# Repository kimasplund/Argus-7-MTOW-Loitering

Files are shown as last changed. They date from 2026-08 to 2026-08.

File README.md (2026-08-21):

Clude and Kimi decided to have a drone baby over night from som questions i asked in group chat about a project kimi swarm chewed over. Seems to be fairly well optimized airframe. Maybe usefull for someone, or maybe its just garbage.

# ARGUS-7 — Persistent Disaster-Zone Communications & Survey UAV

Long-endurance fixed-wing UAV carrying a 50 kg multi-role bay (LTE/5G relay +
EO/IR gimbal + mesh/satcom backhaul) over a disaster zone, recovered by parachute
and airbag for reuse.

**Status:** paper design with a reproducible model behind it. Nothing flight-tested,
no CFD, no structural test. 459 tests pass; 12 xfails document real defects in the
published design rather than broken tests.

## The aircraft

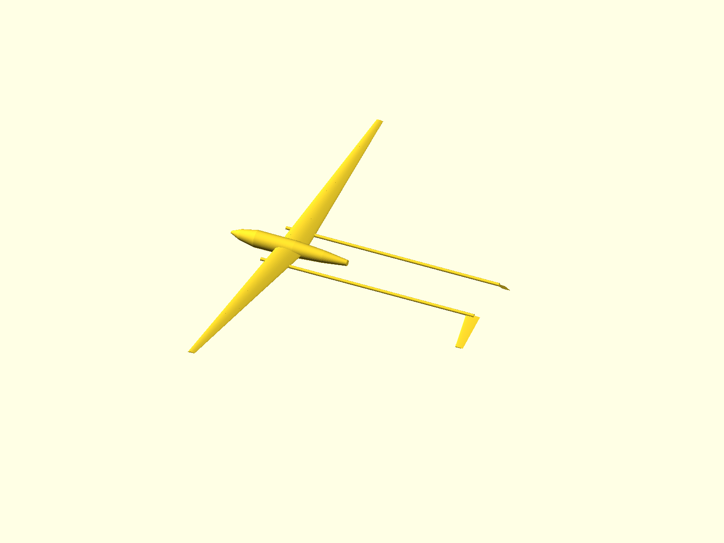
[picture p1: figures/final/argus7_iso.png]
ARGUS-7 v5.0 isometric


| | |
|---|---|
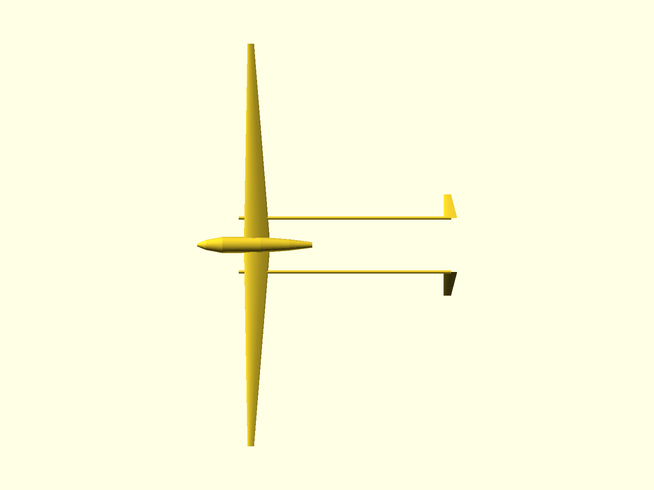
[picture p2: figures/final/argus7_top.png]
top
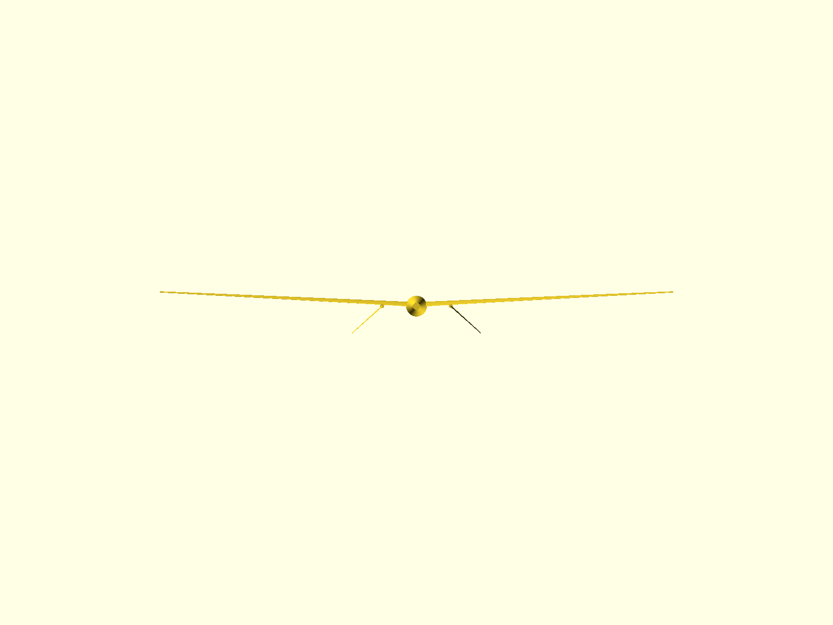
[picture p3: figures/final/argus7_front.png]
front
|  |  |

**v5.0** — 6.97 d loiter, 320 kg MTOW, 11.86 m span, 5.72 m² wing at AR 24.6,
10.85 kW engine driving a 1.04 m two-blade propeller at 2050 rpm through 3.66:1.
Static margin +12.72% full / +13.68% dry. **Passes 8 of 9 adoption gates** — G7
(buildability) fails because its 251 g/kWh full-load BSFC is a design *target*,
not a verified figure for any engine on the report's shortlist; the nearest
verified units are 330 g/kWh.

The wing sits at 41% of fuselage length, not the 22% the published design used.
That single change is what makes it balance, and it also puts the tanks at the CG,
so CG travel across the whole fuel burn is +0.94% MAC.

Renders regenerate from `design/argus7_v5.yaml` via `scripts/build_model.py`.
**These depict a paper design that has never been built or flown**, and
`docs/argus7_v3_premortem.md` lists what would have to be true for it to fly.

## Performance

Two different missions, two different speeds. Endurance flies at minimum *power*;
range flies at minimum *drag*. You do not get both from one flight.

| | Loiter mission | Ferry mission |
|---|---|---|
| **Endurance** | **166.6 h (6.94 d)** | 131.8 h |
| **Range** | — | 17,659 km **(not currently flyable — see below)** |
| Speed | ~102 km/h TAS | 134 km/h TAS |
| Best-range band | — | 124–146 km/h (within 1%) |
| L/D max | 30.4 at C_L 1.028 | |

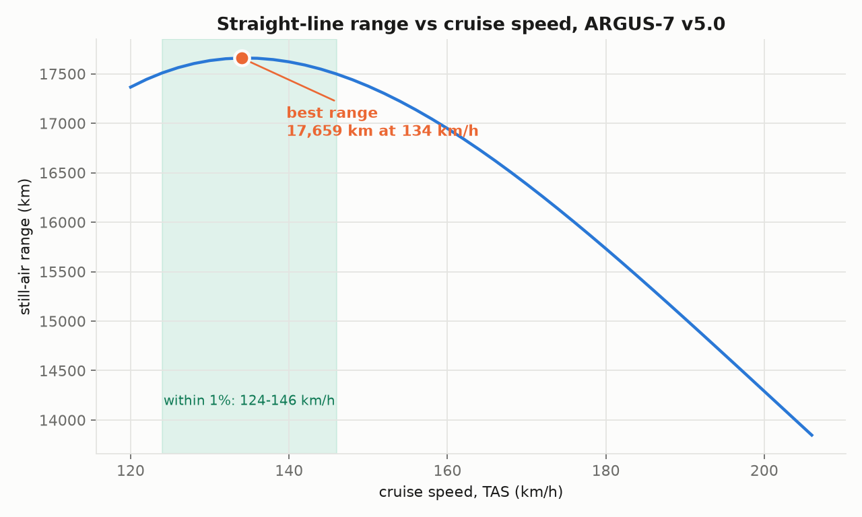
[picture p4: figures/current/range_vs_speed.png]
range vs speed


The range optimum sits *faster* than textbook L/D would put it, because BSFC
depends on engine load fraction — cruising harder works the engine into a better
part of its curve.

**What 17,659 km reaches**, from a mid-Europe base: Lisbon 19%, New York 37%,
Tokyo 44%, Cape Town 56%, Sydney 86%. Earth's circumference is 227% — no.

**Sanity check:** Vanilla VA001's 8-day world record at 191 kg is roughly
19,300 km of air distance if flown straight, so this is the same order as a real
aircraft of the class. It is *not* the discredited 16,000 km claim from the
originating session revived — that was 200 kg on BSFC 230 g/kWh with no stall
margin; this is 320 kg on ~310 g/kWh part-load with the stall margin active.

**The range figure is not flyable with the propeller as specified.** Reaching
134 km/h at MTOW needs 2,500 prop rpm, i.e. 9,148 crank rpm through the 3.66:1
reduction — **122% of the assumed 7,500 rpm rating**. The fixed-pitch disc was
selected for the loiter point and tops out near 122 km/h at MTOW, leaving much of
the installed power unusable in cruise. The loiter mission is unaffected. This is
the case where the earlier "variable pitch buys nothing" conclusion stops holding:
it was true for loiter, and is false for the ferry mission.

**Other caveats:** still air (a 30 km/h headwind costs 22% of range); no reserve,
climb, descent or diversion, fuel burned to dry tanks; and 102 km/h does not close
at MTOW — the loiter speed only becomes available once fuel has burned off.
Regenerate with `scripts/range_analysis.py`.

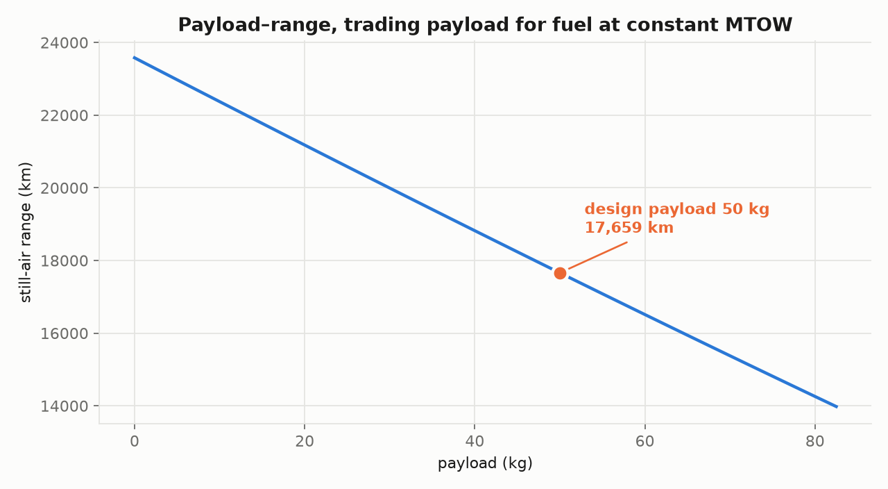
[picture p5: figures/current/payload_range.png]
payload-range


## Start here

- **[docs/decisions/](docs/decisions/)** — what was found, decided and corrected,
  with the reasoning and the cost of being wrong for each.
- **[docs/argus7_design_report.md](docs/argus7_design_report.md)** — the original
  v1.0 report. **Superseded**: it publishes a statically unstable aircraft. Kept as
  the historical record.
- **[design/](design/)** — the design points. See the lineage below.

## Design lineage

These are not variants of one aircraft; they are successive corrections.

| File | Endurance | Status |
|---|---|---|
| `argus7_v1.yaml` | 4.70 d published, **3.16 d** measured | **Published, defective.** Statically unstable (−44% → −82% MAC), wing cannot hold its fuel, propeller cannot absorb its engine |
| `argus7_v2.yaml` | 4.88 d | **RETIRED.** Unstable (−8.7% → −23.5%), mass budget 13 kg short |
| `argus7_v3.yaml` | 6.33 d | **Superseded.** Balances, but at +5.79% MAC — below the spec's own 8% floor |
| `argus7_v4.yaml` | 6.99 d | **Superseded.** Balances, but span 12.001 m against a 12.0 m limit — zero buildable margin, fails gate G3 |
| `argus7_v5.yaml` | **6.94 d** | **Current. 8/9 gates** — G7 fails on an unverified engine BSFC. Span 11.856 m (144 mm margin), SM +12.72% / +13.68%, mass closes exactly |

Every design point is machine-checked: geometry closure, provenance tags on every
parameter, and a static-margin verification against `argus7/analysis/balance.py`.

## The five findings that moved the numbers

1. **The engine is the biggest lever, not the airframe.** v1.0 installs 17 kW for
   climb, then loiters at 3.4 kW — **19% load, where BSFC is 425 g/kWh, not the
   assumed 270**. Right-sizing to ~11 kW is worth more than every aerodynamic
   refinement combined.
2. **The aircraft did not balance, and nobody had checked.** Static margin
   −44% MAC at full fuel. The report's published "+14.7% at CG 42%" does not
   reproduce; the *neutral point* half of that same line does, so the 42% CG was an
   assumed target no mass build-up supports. Fixed by moving the wing station from
   `x_le_frac` 0.22 to ~0.42.
3. **The wing could not hold its own fuel.** 101.5 kg required against 66 kg of
   capacity. Fixed by a larger, thicker wing — which also buys spar depth, so empty
   mass barely moves.
4. **The propulsion set did not close.** A 0.813 m prop at 2100 rpm needs
   C_P = 0.911 against a ~0.25 ceiling. It was a symptom of the oversized engine:
   at 11 kW an ordinary 1.04 m two-blade prop absorbs it comfortably.
5. **Aspect ratio is not the lever the design was built around.** Span efficiency
   is nearly flat in AR (0.989 at AR 14 to 0.969 at AR 30, measured across 45 AVL
   runs), so the only real cost of aspect ratio is structural mass.

## Layout

```
argus7/
  design/    parameter schema, geometry derivation, closure guards
  cad/       aerofoil coordinates, build123d model, STEP/STL/OpenSCAD export
  aero/      XFOIL driver, NeuralFoil surrogate, component drag build-up
  prop/      engine power and part-load BSFC, BEMT propeller
  mission/   ISA atmosphere and the batched differentiable mission simulator
  opt/       design space, mass model, geometry coupling, layout, optimiser
  analysis/  CG, neutral point, static margin (AVL-cross-checked)
research/    materials, riblets, boom construction, empennage trade, hypotheses
docs/decisions/   rulings, findings, gauntlet pre-registration and audit
scripts/     setup_env.sh, build_model.py, optimiser runs, mutation_test.py
opt_runs/    raw output of every optimisation run
```

## Reproducing

```bash
./scripts/setup_env.sh                      # xfoil, avl, gmsh, calculix, SU2, openscad, venv
PYTHONPATH=. .venv/bin/pytest tests/ -q     # 459 pass, 12 xfail
PYTHONPATH=. .venv/bin/python scripts/build_model.py    # regenerate CAD from design/argus7_v1.yaml
PYTHONPATH=. .venv/bin/python scripts/mutation_test.py  # test the tests
```

The mission simulator reproduces the closed-form Breguet solution to **0.0000%**
and the published v1.0 endurance to **+0.2%**. It runs 40 M designs in 4.6 s on a
12 GB GPU with exact gradients through the fuel-burn integration.

## Figures

| Path | Status |
|---|---|
| `figures/cad/` | v1.0 renders, regenerated by `scripts/build_model.py` |
| `figures/cad_v2/` | v2.0 renders — **v2.0 is retired**, kept only for comparison |
| `figures/argus7_3view.png`, `argus7_performance.png` | v1.0 era, from the originating session. **Not regenerable** — the code did not survive |
| `figures/design-pack/fig1`–`fig9` | The 200 kg AR-20 predecessor, a different aircraft. **Not regenerable** |
| `figures/final/` | v5.0 renders, regenerated by `scripts/build_model.py` |
| `figures/current/` | Static margin, part-load BSFC, endurance, drag split, range, payload–range — all regenerated by `scripts/make_figures.py` and `scripts/range_analysis.py` |

## Known gaps

- **The MTOW scaling law is not determined.** Three fits of the same quantity give
  exponents 0.869, 0.998 and 1.452 depending on the subset. Only engine power scales
  cleanly (MTOW^0.82, 6.1% scatter) because climb pins it; span, area and aspect
  ratio scatter 20–31% because the objective is genuinely flat in those directions.
  See [docs/decisions/2026-08-21-scaling-not-determined.md](docs/decisions/2026-08-21-scaling-not-determined.md).
- **Report §2's tail row does not close:** V_h is 0.5765, not the stated 0.68.
  Tracked as an xfail.
- **Two of the report's three sensitivity anchors are wrong:** BSFC 250 gives
  +0.377 d, not +0.5 d; 3,000 m gives +0.198 d, not +0.23 d. Only the C_D0 anchor
  reproduces.
- **The performance analysis behind the v1.0 report is not reproducible** — the code
  did not survive the originating session. The CAD and the current mission model are.
- **The endurance case rests on a BSFC measurement nobody has made.** 335 g/kWh at
  ~31% load is modelled, not dyno-mapped.
- Model limits on every endurance number: pure loiter only (no transit, climb or
  reserve), fuselage fixed at 3.4 m, non-wing airframe mass fixed at 28 kg
  regardless of wing size, mass model calibrated on a single point.
- Regulatory treatment is EU headline level only, and the current design point sits
  **above** the 250 kg band the original occupied.

## Verified non-issues

- **Propeller/boom clearance.** The booms sit outboard of the prop disc and move
  outboard automatically with wing span, because `booms.y_station_frac` is a
  fraction of semi-span. Clearance is 169 mm on v1.0 and improves on later points.
- **The booms are not in the propwash.** An earlier revision of this file claimed
  they were. They clear the contracted slipstream by 183–209 mm, giving a vibratory
  strain of 0.011% against a 0.6% matrix fatigue limit — a 55× margin. The design
  action is a prohibition (no structure inside r = 0.45 m aft of the disc), not a
  layup constraint.
- **Wing thickness at 20%** costs +15.8% on wing profile drag and *raises* C_Lmax
  from 1.868 to 1.973. Measured on the real coordinates, not assumed.

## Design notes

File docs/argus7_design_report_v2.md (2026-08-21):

# ARGUS-7 — Persistent Disaster-Zone Communications & Survey UAV
## Engineering Design Report (v2.0 of the report; design point v5.0)

**Date:** 2026-08-21 · **Design point:** `design/argus7_v5.yaml` (variant tag `v5.0`)
**Status:** Paper design. Nothing here has been built, flown, wind-tunnel tested, or meshed for CFD.
There is now a first pass of structural analysis (§6) — analytic, cross-validated, and
carrying one finding that makes the mass model optimistic. The finite-element model
built alongside it **does not reproduce the cross-validated answer and its numbers are
not used anywhere in this report.**

---

> ### This report supersedes `docs/argus7_design_report.md` (v1.0).
>
> That document remains in the repository as the historical record and must not be
> edited. It should not be used as a design reference. It publishes an aircraft that
> is **statically unstable at every fuel state** (−44.0% MAC full, −82.2% MAC dry),
> whose **wing cannot hold its own fuel** (101.5 kg required into 66.1 kg of tank),
> whose **propeller cannot absorb its engine** (C_P 0.911 demanded against a ~0.25
> practical ceiling), whose **§2 tail row does not close** (V_h 0.5765, not the stated
> 0.68), and **two of whose three published sensitivity anchors are wrong**. Its
> headline 4.70-day endurance is 3.16 days once the engine is modelled at the load it
> actually runs at instead of assumed. Every one of those statements is measured, and
> §10 gives the arithmetic and the file for each.

> ### An earlier revision of *this* report published v3.0. That design point is superseded twice over.
>
> v3.0 balanced, but at **+5.79% MAC** — below the programme's own pre-registered 8%
> static-margin floor, because the optimiser had been run with a 5–15% window instead
> of the spec's 8–20%. v4.0 fixed the stability gate and then landed at **12.0015 m of
> span against a 12.0 m limit** — 1.5 mm over, which is zero buildable margin and a
> failed gate G3. **v5.0 is the current design point.** Every number in this report is
> v5.0's unless it is explicitly labelled otherwise. §9 gives the lineage.

---

## 0. Executive summary

ARGUS-7 v5.0 is a 320 kg MTOW, single-engine, high-aspect-ratio, twin-boom pusher UAV
sized to loiter over a disaster zone carrying a 50 kg / 500 W multi-role
communications and survey bay, recovered by parachute. It is the output of an
11-variable optimiser that owns the **layout** as well as the wing, and that treats
longitudinal static margin, wing fuel volume, climb power and span as hard
constraints rather than as things checked afterwards.

| Headline | Value | Where it comes from | The caveat, stated next to it |
|---|---|---|---|
| **Loiter endurance** | **6.97 d (167.3 h)** | `opt_runs/layout_final.json` (`refined`), reproduced here to 167.325 h from the recorded design variables | **Pure loiter only** — no transit, climb, reserve or wind. The recorded figure is computed at **η_prop 0.858**, hardcoded in the run script; at the propeller efficiency **the design file itself records (0.8529)** it is **166.56 h (6.94 d)**, and with BSFC evaluated pointwise across the burn rather than frozen, **159.98 h (6.67 d)**. See §7.3 |
| Loiter altitude | 4,000 m | optimiser variable, at the lower bound of the run that produced this point | Inside the sponsor-locked 3,000–4,500 m band. Coverage 10.81 km radius / 367 km², on v1.0 §8's own unvalidated elevation model — the same as v1.0's design point, and 16% less area than v3.0's 4,359 m |
| MTOW | 320.00 kg | `design/argus7_v5.yaml`, and it is **at the optimiser's upper bound** | **+28% on v1.0's 250 kg.** This crosses the mass band v1.0 §9's entire regulatory case was built at. Declared here, see §12.4 |
| Wing | 5.7201 m², AR 24.573, span 11.8558 m, taper 0.25, t/c 0.220 | design file; closure verified by `argus7.design.geometry` to 1e−9 | Span is inside the 12 m transport gate with **144 mm** of margin. **Taper 0.25 and t/c 0.22 are both outside the ranges the aero surrogates were fitted over** — §3.4, §3.5 |
| Static margin | **+12.72% MAC full, +13.68% dry**, travel **+0.95% MAC** | `argus7.analysis.balance` on the design file | **Inside the spec's 8–20% MAC window on all four readings available** (+8.23% to +17.96%, §5.4) at both fuel states. This is the first design point in the programme of which that is true |
| Fuel | 172.42 kg into a 190.44 kg wing tank | `argus7.opt.design_space.wing_fuel_capacity_kg` | **+18.02 kg (10.4%) margin**, against v3.0's 4.4%. Survives mogas density (+5.5%) where v3.0 did not — §12.2. The capacity model is three fractions, two of them measured, not a lofted cavity |
| Mass closure | **0.00 kg** residual on 320.00 kg | `argus7.analysis.balance.mass_budget_residual_kg` | Exact to the design file's own precision |
| Engine | 10.849 kW rated, 30.0% loiter load, **effective BSFC 339.3 g/kWh** | optimiser; cross-checked against `argus7.prop.engine`, which gives 350.1 g/kWh at the same shaft power (3.2% apart) | The 339 rests on a **full-load BSFC of 250 g/kWh, which is the report's aspirational dyno target, not a measured unit.** Both shortlist engines with *verified* BSFC are 330 g/kWh, at which this aircraft flies **5.26 d**, §4.4 |
| Propeller | 1.04 m, 2 blades, 2,050 rpm, p/D 0.95, η 0.8529, 3.659:1 reduction | design file; re-solved at **this** design point, not inherited | **A found-and-fixed defect** — v3.0 carried v2.0's propeller and was 26% short of level-flight thrust (§4.5). v5.0's disc meets loiter thrust and absorbs 101% of the rating at climb. **But it cannot turn fast enough for the ferry mission** — §8.4 |
| C_D0 | 0.01690 | `argus7.opt.coupled.cd0_from_geometry` | Contains **no** payload turret, cooling drag, or base drag. A modest +0.0035 allowance costs **−0.43 d** — §3.2 |
| **Tip deflection at limit** | **855 mm = 14.4% of semi-span** | `scripts/structural_analysis.py`, cross-validated to 0.2 points against `research/materials_pack.md`'s independent estimate | Sailplane territory, not light-aircraft territory. Not disqualifying; it interacts with spanload, control effectiveness and flutter, none of which is modelled coupled — §6.2 |
| **Compression-cap buckling** | **critical at 80 MPa against 600 MPa applied — margin −87%** | `fea_runs/structural.json`, corroborated independently by the cap's width-to-thickness ratio | **The mass model is optimistic.** A buckling-sized cap is heavier than a strength-sized one and wing mass feeds straight into endurance — §6.3 |
| Best range | **17,659 km at 134 km/h TAS**, 131.8 h aloft | `opt_runs/range.json`, `scripts/range_analysis.py` | Still air, no reserve, burned to dry tanks — and **the recorded fixed-pitch propeller and 3.659:1 gearing cannot reach that speed** at the engine's assumed rpm rating, §8.4 |

### The honest bottom line

**v5.0 is the first design point in this programme that passes every closure the
repository can evaluate simultaneously**: it balances, inside the pre-registered
window rather than merely positively; it holds its fuel with real margin; its mass
budget closes exactly; its span is inside the transport gate with buildable margin;
and its propeller was solved at its own operating point instead of inherited from a
retired aircraft. Each of those was false of at least one of v1.0, v2.0, v3.0 and v4.0.

**Two things are still open, and neither is aerodynamic.**

**First, the engine.** 6.97 days is the *optimistic* end of a defensible band, and the
report says so here rather than in a footnote. Stacking the corrections this
repository can already justify:

| Applied cumulatively to the recorded design point | Endurance |
|---|---|
| As recorded (`opt_runs/layout_final.json`, η_prop 0.858) | **167.32 h — 6.97 d** |
| + the propeller efficiency the design file itself records (0.8529) | 166.56 h — 6.94 d |
| + the load fraction recomputed at that efficiency (29.62%, 340.8 g/kWh) | 165.80 h — 6.91 d |
| + BSFC evaluated pointwise along the burn instead of frozen at mid-load | 159.98 h — 6.67 d |
| + a +0.0035 C_D0 allowance for turret, cooling and base drag | 153.69 h — **6.40 d** |
| + a **verified** engine's 330 g/kWh full-load BSFC instead of the 250 target | 116.43 h — **4.85 d** |

**The programme's 5–7 day ambition is met with room to spare on the modelled engine,
and missed — narrowly, at 4.85 days — on the only engines whose fuel consumption
anybody has measured.** That is a materially better position than v3.0, which fell to
4.46 d under the same stack, but it is the same finding: the design lives or dies on a
dyno, not on aerodynamics.

**Second, the structure.** The first structural analysis in the programme's history
(§6) returns a wing that deflects **14.4% of semi-span at limit load** and whose
compression caps buckle at **an eighth of the stress the material allowable assumes**.
The deflection is large but survivable. The buckling is not a caveat, it is a
correction: **the wing mass model is optimistic, and wing mass converts to endurance
at 1.51 h/kg** (§6.5). Nothing in this report has been re-run with a buckling-sized
cap, because sizing one properly is a design task, not an analysis task.

### The pre-registered gates

Unlike every previous revision of this report, this section is short.

Running the eight gauntlet gates (`docs/decisions/2026-08-20-gauntlet-preregistration.md`)
plus the spec's separate stability window against v5.0:

| Gate | v5.0 | Verdict |
|---|---|---|
| G1 endurance ≥ +5% on the champion | 167.3 h vs 75.9 h honest / 112.98 h published | ✅ +48% |
| G2 fuel ≤ wing tank capacity | 172.42 ≤ 190.44 kg (+10.4%) | ✅ |
| G3 span ≤ 12 m | 11.8558 m (144 mm margin) | ✅ |
| G4 mass closure | 0.00 kg residual | ✅ |
| G5 AR^1.5 wing-mass scaling honoured | yes | ✅ |
| G6 regulatory band declared | 320 kg, declared in §12.4 | ✅ |
| G7 buildability: AR ≤ 25, span ≤ 12 m, **engine matched to a real §6 unit** | AR 24.57 ✅, span ✅, **engine is a 250 g/kWh target** | ❌ **FAIL** |
| G8 stall margin | loiter C_L 1.2098 = C_Lmax/1.15² exactly | ✅ (binding) |
| Spec line 109: 8% ≤ SM ≤ 20% MAC | **+12.72% full / +13.68% dry**, and 8.23–17.96% across every reading | ✅ |
| Annex A tripwire #3: loiter BSFC ≤ 300 g/kWh | **339.3 g/kWh modelled** | ❌ **trips** |

**Eight of the nine gates pass. G7 does not, for exactly the reason it did not pass on
v3.0 and on the challenger before it: the design rests on a full-load BSFC of
250 g/kWh that report §6 itself describes as a target, and the gauntlet audit already
ruled that a target is not a unit** (`docs/decisions/2026-08-20-gauntlet-audit.md` §G7).
Nothing about the engine has changed between v3.0 and v5.0; the airframe changed
around it.

**`README.md` currently states that v5.0 passes 9/9. On the repository's own record it
passes 8/9,** and the ninth is the one gate that no amount of optimisation can close.
The honest statement is narrower than "v5.0 is the design": **v5.0 is the best design
point this programme has produced and verified, it clears every airframe gate, and the
one gate it fails is about an engine nobody has put on a dyno.**

---

## 1. Mission and requirements

Unchanged from v1.0 §1. Restated so this document is self-contained.

- **Payload:** 50 kg multi-role bay — LTE/5G relay (eNB plus sector antennas), EO/IR
  gimbal (TrakkaCam TC-300 class), mesh MANET feeder, LEO/Iridium backhaul, mission
  computer and power conditioning. **50 kg / 500 W continuous, ~620 W peak**, all
  COTS-derived. Tagged `report-§1` and `report-§3` in the design file's provenance
  block.
- **Modes:** (A) *Local* — launch near the zone, pure loiter. (B) *Deploy* — transit
  to the zone, loiter, recover locally. **Only mode A is modelled as a mission.**
  Every endurance figure in this report is mode A. §8 adds a straight-line **ferry**
  calculation, which is a third thing and is not mode B either — it has no loiter
  segment at all.
- **Recovery:** parachute plus airbag, reusable airframe, no single-use elements.
- **Environment:** loiter band **3,000–4,500 m AGL**, −5 to −15 °C at altitude.

The loiter band is a locked requirement, and it is treated as one here. The retired
v2.0 optimiser went 500 m *below* the floor to buy 8 hours, giving up 61% of the
coverage area, because nothing in its objective knew coverage existed. The run that
produced v5.0 was bounded at [4,000 m, 4,500 m] and returned **4,000 m** — the floor of
its own search, because at fixed lift coefficient a denser atmosphere means a slower
loiter and less power. **The bound is what stops it going lower, not the physics**, and
that is worth saying plainly: altitude is a coverage requirement fighting an endurance
gradient, and the requirement is winning only because it was written down.

**Coverage at the v5.0 loiter altitude,** on v1.0 §8's own suburban elevation-angle
model (θ* = 20.3°): service radius **10.81 km**, area **367 km²**. That is identical to
v1.0's 4,000 m design point and **16% less area than v3.0's 4,359 m** — a real
regression against the superseded design point, bought for +0.28 d of endurance
(§7.4). The elevation model itself is unchanged and unvalidated; v1.0 §8 already flags
that no published measurement exists in this altitude band.

---

## 2. The v5.0 configuration

### 2.1 Geometry

Every row below is either read directly from `design/argus7_v5.yaml` or derived from
it by `argus7.design.geometry`, which enforces closure to 1e−9. Nothing is typed in.

| Parameter | v3.0 (superseded) | **v5.0** | Provenance |
|---|---|---|---|
| MTOW | 312.93 kg | **320.00 kg** | derived (optimiser); **at its upper bound** |
| Wing area S | 5.9191 m² | **5.7201 m²** | derived |
| Aspect ratio AR | 21.442 | **24.573** | derived |
| Span b | 11.266 m | **11.8558 m** | closure identity √(AR·S) |
| Taper ratio λ | 0.697 | **0.250** | derived — **at the search's lower bound** |
| Root / tip chord | 0.6192 / 0.4316 m | **0.7720 / 0.1930 m** | closure |
| MAC | 0.5310 m | **0.5404 m** | closure |
| MAC leading edge | x = 1.2485 m | **x = 1.4269 m** | derived |
| Wing loading | 52.87 kg/m² | **55.94 kg/m²** | derived |
| Airfoil | FX 63-137 at t/c 0.1909 | **FX 63-137, scaled to t/c 0.2200** | section `report-§2`; thickness derived, **at its upper bound** |
| Twist (tip) / dihedral / LE sweep / incidence | −3° / +3° / 1° / 2° | unchanged | **all four tagged `assumption`** — no source in report or research packs |
| **Wing station `x_le_frac`** | 0.3536 | **0.4075** (root LE at x = 1.3855 m) | **derived — this is the single change that makes the aircraft balance** |
| Wing vertical offset | +8 mm | unchanged | assumption; makes this a mid-wing aircraft |
| Fuselage | 3.4 m × 0.48 m, 6-station loft, 0.4022 m³ | unchanged | **assumption, unchanged from v1.0 and fixed for every design point** |
| Booms | Ø90 mm, y = ±0.7548 m, length 4.064 m | **Ø90 mm, y = ±0.7943 m, length 6.2497 m** | diameter and station `assumption`; length derived |
| Tail | inverted V, −42° dihedral, panel AR 3.0, taper 0.55, NACA 0010 | unchanged | type `report-§2`; angles `assumption` |
| Tail effective horizontal area S_h | 0.3698 m² | **0.3222 m²** | derived |
| Tail arm | 3.5847 m = 1.0543 × L | **5.7732 m = 1.6980 × L** | derived |
| **Tail volume coefficient V_h** | 0.4218 | **0.6018** | derived, and it **closes** — see §10 |
| Engine | 10.845 kW | **10.849 kW**, 250 cc nominal displacement | power derived; displacement inherited `report-§2` |
| Reduction | 3.947 : 1 | **3.659 : 1** | derived |
| Propeller | 1.04 m, 2 blades, 1,900 rpm, p/D 0.95 | **1.04 m, 2 blades, 2,050 rpm, p/D 0.95** | derived (BEMT), **at this design point** |
| Loiter altitude | 4,358.8 m | **4,000.0 m** | derived |

**A note on the tail arm, because it has nearly doubled.** At 1.698 × fuselage length
the tail quarter-chord sits at x = **7.335 m — 3.94 m aft of the 3.4 m fuselage
tailcone**, against v3.0's 1.57 m, carried on booms **6.25 m** long
— 54% longer than v3.0's and 71% longer than the 3.646 m boom on which
`research/boom_construction_pack.md` sized the whole boom structure. That long arm is
what buys V_h 0.6018 and the +29.5% MAC tail contribution the neutral point needs, and
it is what allows a *smaller* tail (0.3222 m² against v3.0's 0.3698) to do more work.
**Every boom number in the research pack is now wrong by more than it was for v3.0.**
The one boom quantity that has been re-derived for v5.0 is torsional frequency, and it
moved: **14.5 Hz against the pack's 22.7 Hz** (§6.6).

**Three of the eleven design variables sit hard against a bound**: MTOW at 320 kg,
t/c at 0.22, taper at 0.25. A fourth, `bsfc_full`, sits at its 0.250 floor. The
premortem's "hidden assumption" finding applies unchanged and with one more variable:
**the answer is partly a description of where the box was drawn.** Taper 0.25 and
t/c 0.22 are additionally *outside the calibration ranges of the aerodynamic
surrogates that price them* (§3.4, §3.5), which is the specific failure class this
report exists to stop repeating.

### 2.2 Mass table

Produced by `argus7.analysis.balance.mass_table` on the design file. The `x` column is
the fuselage station of each group's centre of gravity; `%MAC` is measured from the
MAC leading edge, which is the convention used throughout this report.

| Item | Mass (kg) | x (m) | % MAC | Moment (kg·m) |
|---|---|---|---|---|
| Wing | 40.63 | 1.6430 | 40.0 | 66.75 |
| Fuselage (incl. misc) | 15.06 | 1.6264 | 36.9 | 24.49 |
| Booms | 9.70 | 4.3603 | 542.9 | 42.29 |
| Tail | 3.25 | 7.3833 | 1102.3 | 23.99 |
| Powertrain | 15.95 | 3.0500 | 300.4 | 48.65 |
| Avionics | 6.00 | 1.4500 | 4.3 | 8.70 |
| Recovery | 7.00 | 0.9500 | −88.3 | 6.65 |
| Payload | 50.00 | 0.4320 | −184.1 | 21.60 |
| **Fuel** | **172.42** | **1.6568** | **42.6** | **285.67** |
| **TOTAL** | **320.00** | **1.6524** | **41.7** | **528.78** |

Design-file MTOW 320.00 kg; **unallocated residual 0.00 kg.**

Design-file grouping, for comparison with v1.0 §3:

| Group | v1.0 | v3.0 | **v5.0** |
|---|---|---|---|
| Airframe structure | 60.5 | 73.39 | **68.63** (wing 40.63 + non-wing 28.00) |
| Powertrain | 25.0 | 15.95 | **15.95** (a 10.8 kW engine, not a 17 kW one) |
| Avionics | 6.0 | 6.00 | 6.00 |
| Recovery | 7.0 | 7.00 | 7.00 |
| Payload | 50.0 | 50.00 | 50.00 |
| **Empty (no payload, no fuel)** | **98.5** | 102.34 | **97.58** |
| Fuel | 101.5 (40.6% of MTOW) | 160.60 (51.3%) | **172.42 (53.9% of MTOW)** |
| MTOW | 250.0 | 312.93 | **320.00** |

**v5.0's wing is 4.76 kg lighter than v3.0's on a 3.4% smaller area and a 5.2% larger
span.** That is not an error; it is what a 22% section buys. The spar is 170 mm deep at
the root against v3.0's 118 mm, and depth buys cap area faster than span and weight
consume it (§6.1). It is also, as §6.3 establishes, exactly where the buckling problem
comes from.

**Two assumptions in that table carry the whole thing, and both are declared:**

1. **Non-wing airframe mass is fixed at 28.00 kg** regardless of how large the wing,
   tail or booms become. It was 28 kg on a 3.9 m² wing with a 3.65 m boom and it is
   28 kg on a 5.72 m² wing with a **6.25 m** boom. The mass table above splits that
   28 kg across fuselage/booms/tail for CG purposes only; the total is a constant.
   Charging it honestly — fuselage ∝ MTOW, booms ∝ length, tail ∝ wetted area,
   recovery ∝ MTOW — puts it at roughly **32.9 kg plus an 8.96 kg recovery system**,
   i.e. **about +6.6 kg the model never charges**, and the boom-length term has grown
   since that estimate was made. At the measured exchange rate of **1.51 h/kg** that is
   **−9.8 h, 166.6 → 156.8 h**. This is the same defect the gauntlet audit found on the
   original challenger. It is not fixed here, and v5.0's 6.25 m booms make it worse
   than it was on v3.0.
2. **The wing mass model is calibrated on one point.** `argus7.opt.design_space`
   derives spar-cap mass from root bending moment with a single fitted coefficient
   `k_cal = 4.2257`, set so the model returns v1.0's published 32.5 kg wing. The
   gauntlet audit verified the AR^1.5 exponent analytically and cross-checked the
   *ratio* between two design points against Raymer's independent GA regression to
   1.0% — but it also established that **76% of the spar-cap term at the baseline is
   the fitted constant**. The scaling survives, because `k_cal` is a pure multiplier
   and cancels from every ratio; the absolute level is calibrated, not derived. **And
   §6.3 establishes that the sizing criterion it implements is the wrong one.**

---

## 3. Aerodynamics

### 3.1 The drag polar and the loiter point

The mission model uses the standard lumped polar

    C_D = C_D0 + C_L² / (π · AR · e)

with C_D0 = 0.016904 and e = 0.81012, both **outputs of geometry** in the optimiser's
coupled model rather than free variables. At the loiter point:

| Quantity | v3.0 | **v5.0** |
|---|---|---|
| Loiter C_L | 1.2098 | **1.2098** = C_Lmax / 1.15², stall-constrained |
| C_D | 0.04150 | **0.04030** |
| **L/D at loiter** | 29.15 | **30.02** |
| **L/D max** | — | **30.42 at C_L 1.0281** |
| Induced share of C_D | 61.7% | **58.1%** |
| ρ at loiter altitude | 0.78856 (4,359 m) | **0.81913 (4,000 m)** |
| TAS, MTOW → dry | 118.7 → 82.8 km/h | **119.8 → 81.4 km/h**, mean 101.8 km/h |
| Drag, MTOW → dry | 105.3 → 51.2 N | **104.6 → 48.2 N** |
| Shaft power, MTOW → dry | 4.71 → 2.04 kW | **4.75 → 1.94 kW**, mean 3.26 kW |
| Re at MAC, MTOW → dry | 8.37e5 → 5.84e5 | **8.87e5 → 6.02e5** |
| Re at tip, MTOW → dry | 6.80e5 → 4.75e5 | **3.17e5 → 2.15e5** |

The **stall constraint binds**, as it did on v1.0 and v3.0: unconstrained minimum-power
C_L for this polar is 1.7806, above C_Lmax/1.15², so the aircraft loiters at 1.2098
exactly. This matters, because loiter speed — and therefore power — is set by C_Lmax,
and C_Lmax is held at a flat 1.60 for every design point.

**The tip Reynolds number is the new exposure, and it is a big move.** Taper 0.25 on an
AR 24.57 wing gives a **193 mm tip chord**, and Re at the tip falls to **2.15 × 10⁵ by
the end of the mission** — against v3.0's 4.75 × 10⁵. Low-Reynolds airfoil behaviour
degrades sharply below about 3 × 10⁵, and a flat C_Lmax of 1.60 applied to a wing whose
tip lives there is a stronger assumption than it was.

**Measured, and it survives — in two dimensions.** NeuralFoil (xxlarge) on the pinned
`data/airfoils/fx63137.dat` coordinates scaled to 22% thickness gives 2D C_Lmax:

| Re | 13.7% section | **22% section** |
|---|---|---|
| 2.2 × 10⁵ (tip, dry) | 1.747 | **2.103** ⚠ |
| 3.2 × 10⁵ (tip, MTOW) | 1.770 | **2.118** ⚠ |
| 8.9 × 10⁵ (MAC, MTOW) | 1.871 | **2.154** |
| 1.0 × 10⁶ | 1.869 | **2.163** |

So the flat 1.60 is **conservative by 31% even at the tip's worst Reynolds number** —
thickness buys more C_Lmax than low Reynolds number takes away. ⚠ marks the two rows
where **NeuralFoil flags itself as extrapolating outside its training distribution**
(analysis confidence 0.825 against its own 0.9 threshold); the two higher-Re rows carry
no such flag. Those two rows should be checked against XFOIL before being leaned on.

**What is not answered by any of this** is three-dimensional: a taper-0.25 wing loads
its tip harder than a taper-0.7 one, tip stall on a highly tapered high-AR wing is a
departure question, and nothing in this stack models tip-stall progression, spanwise
boundary-layer drift, or the washout needed to control either. The −3° tip twist in the
design file is tagged `assumption` and was not chosen for this planform.

**81.4 km/h at end of mission is slow.** At 22.6 m/s, station-keeping margin against
wind over a disaster zone is thin, and it is slower than v3.0's already-thin 82.8 km/h.
Nothing in the objective function knows about wind. This is a mission-suitability
caveat on the last third of the endurance, not a modelling error.

### 3.2 C_D0 build-up

`argus7.aero.buildup` computes a component parasite build-up from the *actual*
geometry — real FX 63-137 arc length, real fuselage station loft, derived boom length,
true (not projected) tail panel area — with a **measured** transition location rather
than an assumed one. Run on the v5.0 geometry:

| Component | S_wet (m²) | Re | x_tr | C_f | FF | Q | C_D0 | share |
|---|---|---|---|---|---|---|---|---|
| Wing | 11.066 | 8.87e5 | 0.546 | 0.00289 | 1.302 | 1.00 | 0.00729 | 53.3% |
| Fuselage | 4.029 | 5.58e6 | 0.100 | 0.00298 | 1.187 | 1.00 | 0.00249 | 18.2% |
| Booms | 3.534 | 1.03e7 | 0.150 | 0.00253 | 1.003 | 1.30 | 0.00204 | 14.9% |
| Tail | 1.184 | 5.26e5 | 0.300 | 0.00412 | 1.212 | 1.05 | 0.00108 | 7.9% |
| Miscellaneous (6%) | — | — | — | — | — | — | 0.00077 | 5.7% |
| **Total** | **19.813** | | | | | | **0.01368** | |

**The booms are now the third-largest drag item, at 14.9% of C_D0 against v3.0's
10.7%.** That is the 6.25 m tail arm arriving in the drag budget. It is charged, and it
is charged at Q = 1.30 for interference — but the booms have not been re-sized, and
§6.6 is a stiffness argument for making them *larger* in diameter, which would charge
more.

**Three things must be said about that number, and none of them is comfortable.**

**(a) It is not the number the design file carries.** The design file's 0.016904 comes
from `argus7.opt.coupled.cd0_from_geometry`, an equivalent-skin-friction model —
C_D0 = C_fe · S_wet/S_ref — calibrated at the v1.0 point and multiplied by a
NeuralFoil-measured thickness penalty. The two disagree by **23.5%** on v5.0, wider
than v3.0's 22%. They disagree because the build-up reads t/c from the *airfoil
coordinates* (13.71%) while the design flies a section scaled to **22.00%**; the
build-up therefore under-charges the wing's wetted area and form factor, and the gap
grows with thickness. The optimiser's number is the one used, and it is the higher
(more conservative) of the two.

**(b) Neither number contains the payload.** `argus7.aero.buildup`'s own docstring
lists what it omits: the 50 kg payload installation (a ~0.3 m gimballed EO/IR ball at
C_D 0.4 on frontal area is **alone worth ~0.007 in C_D0**), engine cooling drag (5–10%
of total on a piston installation), fuselage base drag (the aft station closes to
r/R = 0.34), and recovery/launch hardware. A modest **+0.0035** allowance for those
costs **−0.43 d** on this design point. The fix is to add the hardware to the design
file, not to raise a factor.

**(c) The correlation is being used outside its calibration.** Raymer's form factor
(eq. 12.30) is a function of t/c and (x/c)_m only — a **minimum-drag** pressure
correlation with no C_L dependence — while the transition location fed to it was
measured **at C_L 1.21**. The module has it both ways, and says so. Cross-checked
strip-by-strip against NeuralFoil on the same coordinates, the C_f·FF build-up was
**11.2% low** on wing drag area at the loiter lift coefficient on v3.0's planform. The
sign of the disagreement with the design file is solid; its size is not.

### 3.3 The XFOIL transition result

The wing transition location is **measured, not assumed** — the one input in this
build-up that is. XFOIL 6.99 on the repository's pinned, checksum-enforced
`data/airfoils/fx63137.dat`, converted Lednicer→Selig, 300 panels, Ncrit 9, viscous,
fixed-C_L mode at C_L = 1.21, ten spanwise stations (`research/riblets_pack.md` §3):

- **Upper surface transition 50.2% chord at the root, moving aft to 60.5% at the tip.**
- Lower surface 61.4% → 68.2%.
- **40.5% of the wing's wetted area is turbulent, carrying 53.3% of its skin friction.**
- Independently corroborated by NeuralFoil (xxlarge), which puts upper transition at
  0.547 (root) to 0.599 (tip).

Two consequences the report must carry:

1. **The laminar run is the leverage, and it is fragile.** Moving upper-surface
   transition forward by five points of chord costs Δc_d ≈ +0.00057 → about **−1.2 h**.
   A fully tripped wing costs on the order of **−14 h**. That is why
   `research/materials_pack.md` §6 is a structures-and-surface question with an
   endurance answer.
2. **Ncrit = 9 is assumed.** A UAV in quiet air at 4,000 m may see Ncrit 11–13, which
   moves transition aft; in turbulent air or propeller wash, Ncrit 5–7 moves it
   forward. The riblets pack flags explicitly that the whole transition table should be
   re-run at Ncrit 7 and 12 before any number in it is treated as settled. It has not
   been.

**And the measurement no longer describes this wing.** These numbers were taken **on
the 13.7% section at v1.0's chords and speeds**. v5.0 flies a **22.0%** section at a
tip Reynolds number less than half v1.0's. Transition on a 22% section is not the same
problem — the pressure recovery is steeper and the separation bubble behaves
differently — and it has not been re-measured. This was a caveat on v3.0; on v5.0 it is
a larger one.

### 3.4 The Oswald factor — three different quantities, and why that mattered

This is the finding that most changed how the programme models drag, and it is
recorded in `docs/decisions/2026-08-20-span-efficiency-finding.md`.

At the loiter lift coefficient, **induced drag is the majority of total drag** (58.1%
on v5.0; 61.7% on v3.0; 55.5% on v1.0). Every optimisation the programme had examined
— riblets, boom deletion, surface finish — was attacking the smaller half. And the
Oswald factor, the single largest lever in the drag model, had never been validated.

AVL 3.36, run on the actual planform at matched C_L 1.21 (12 sections, 24 spanwise
panels, tip-bunched, inside the single-precision NaN limit of 40), returned
**e = 0.9786** at the as-designed −3° twist on v1.0's planform. The design file said
0.85. A crude AeroSandbox viscous subtraction implied 0.77.

**These are three different quantities and must not be compared:**

| Symbol | What it is | v1.0 value |
|---|---|---|
| AVL's e | **Inviscid span efficiency** — how close the lift distribution is to elliptic | 0.9786 |
| The design file's e | **Lumped Oswald factor** in C_D = C_D0 + C_L²/(πARe), which conventionally also absorbs viscous lift-dependent drag | 0.85 |
| AeroSandbox's implied value | A viscous build-up's lumped equivalent, crude subtraction | ~0.77 |

Treating AVL's 0.9786 as if it were the design file's 0.85 would have handed the
programme **+7 h that does not exist**, straight into the optimiser's objective.

**How it was closed.** `argus7.opt.coupled` fits a surface to **45 AVL runs** spanning
AR 14–30, **taper 0.30–0.60**, twist 0 to −6°, and adds an explicit viscous
lift-dependent term:

    1/e_eff = 1/e_inviscid + K_visc · π · AR,   K_visc = 0.002237

calibrated once so the baseline reproduces the report's own total C_D at C_L 1.21. On
v5.0's planform this returns **e_inviscid = 0.9419** and **e_eff = 0.8101**.

**What the AVL sweep established, and it contradicts the design's founding premise:**
span efficiency is **nearly flat in aspect ratio** — 0.989 at AR 14 to 0.969 at AR 30.
The previous optimiser had used Raymer's straight-wing correlation, fitted to
conventional aircraft at AR 5–10, which returns e = 0.485 at AR 22 against 0.979
measured, and it drove a run to AR 15.25 for an entirely fictitious reason. **High
aspect ratio was never the route to endurance it was assumed to be**; the only
legitimate pushback on AR is structural mass, and the only legitimate reward is span.

**Four caveats on the surface, and one of them is new to v5.0:**

- The stored table **reproduces to four decimals** when the decks are rebuilt from
  scratch — the 45-run sweep is real, not asserted.
- **It is not panel-converged.** On a test planform e falls monotonically with
  refinement, 0.9611 (12×24) → 0.9564 (12×36), i.e. −0.5% and still moving. The whole
  surface is built on the coarsest of those, and its coefficients are quoted to six
  figures they have not earned.
- **`K_visc` is design-independent and double-books.** It is calibrated once on a
  13.7% section at Re 7.75e5 and applied unchanged to a 22.0% section at less than half
  that tip Reynolds number. It also overlaps the thickness drag multiplier: the wing's
  profile drag at lift is represented twice, in two terms neither of which knows about
  the other.
- **NEW, and it is an extrapolation the previous revision of this report did not have
  to declare: v5.0's taper ratio is 0.25, below the 0.30 floor of the 45 runs the
  surface was fitted to.** The fit is a quadratic in (λ − 0.45); at λ = 0.25 the
  quadratic term is being read 0.05 outside its data on the steep side. It is also
  below `argus7.opt.design_space.Bounds`'s own taper floor of 0.30 — the layout run
  script carries a wider box than the specification's. The direction of the error is
  not knowable from inside the fit.

**The open band on the lumped Oswald factor — 0.77 to 0.85 — is worth about −3.8 h on
v5.0** (e = 0.77 gives 162.8 h against the baseline 166.6 h). Narrower than it was on
v3.0, because v5.0's higher AR reduces the induced share. It has been narrowed by
measurement, not closed.

### 3.5 The thickness penalty is also being read outside its data

`argus7.opt.coupled.thickness_drag_multiplier` prices wing thickness from a NeuralFoil
measurement on the actual coordinates at **t/c 0.137, 0.150, 0.170, 0.190 and 0.200**,
fitted as `1 + 2.5·(t/c − 0.137)`, linear to within 0.5% across that range.

**v5.0 flies t/c 0.220.** That is 10% beyond the last measured point, on a linear
extrapolation of a quantity (profile drag versus thickness) that is not linear
indefinitely — it steepens as the section approaches separation-limited pressure
recovery. The multiplier is therefore **likely to be optimistic**, and the model has no
way to know by how much. Re-measuring at t/c 0.22 and 0.24 is a NeuralFoil run of a few
seconds and has not been done.

This is the same class of error as Raymer's Oswald correlation at AR 22 (§3.4) and as
the propeller carried from v2.0 (§4.5): **a constant used at a point it was not
evaluated for.** It is listed here rather than in §12 because it prices a variable that
sits hard against its bound.

---

## 4. Propulsion

### 4.1 Why v1.0's propulsion set could not close

v1.0 specified a **0.813 m propeller at 2,100 rpm against a 17 kW engine**. The power
coefficient that demands is

    C_P = P / (ρ n³ D⁵) = **0.911**

against a practical ceiling near 0.25 for a two- or three-blade disc of that
proportion. Swept across every pitch a real propeller could be built with and across
advance ratio, the best C_P that disc reaches is far below what the rated power
demands: **it can absorb about 4.7 kW of 17.** Asserted, not merely claimed, by
`tests/test_bemt.py::test_required_cp_for_the_report_baseline_is_0_911` and
`::test_report_propulsion_set_cannot_absorb_rated_power`.

**The propeller was never the real defect.** It was being asked to absorb an engine
sized for *climb* while flying a *loiter* mission. That tension — climb wants 11–17 kW,
loiter wants 3.3 kW, one fixed-pitch propeller on one fixed engine must serve both —
is the central configuration problem of this aircraft. §8.4 shows it is still not
solved: the same fixed set that serves loiter cannot serve the ferry mission either.

### 4.2 Engine right-sizing

The single largest lever in the whole programme is the **engine rating**, not the
airframe.

| | v1.0 published | v1.0, honest model | v3.0 | **v5.0** |
|---|---|---|---|---|
| Engine rating | 17 kW | 17 kW | 10.845 kW | **10.849 kW** |
| Loiter shaft power (mean) | ~3.4 kW | 3.25 kW | 3.30 kW | **3.26 kW** |
| **Load fraction (mid-burn)** | — | **19.0%** | 30.6% | **30.0%** |
| BSFC assumed / effective | 270 assumed flat | **425 g/kWh** | 339 g/kWh | **339 g/kWh** |
| Endurance | 4.70 d (claimed) | **3.16 d** | 6.33 d | **6.97 d** |

Source: `opt_runs/final.json` (`baseline_v1`, 75.90 h = 3.163 d) and
`opt_runs/layout_final.json`.

Right-sizing works because BSFC is a strong function of load. A 17 kW engine loitering
at 3.3 kW is at 19% load, deep in the hyperbolic part of the fuel-flow curve. An
11 kW engine at the same shaft power is at 30%, where the curve has flattened.

The climb constraint is what stops the engine shrinking further, and on v5.0 it is
**very nearly exactly active**: `argus7.opt.coupled.climb_power_required_w` returns
**10.839 kW** for 2 m/s sea-level climb at MTOW against the **10.849 kW** installed.
That is **+0.09% margin** — tighter than v3.0's 1.5%, and another way of saying the
engine size is *determined* by the climb requirement and not by the loiter mission at
all. It also means the engine rating has no headroom whatsoever for the +6.6 kg of
uncharged airframe mass in §2.2, for a buckling-sized spar (§6.3), or for a real
propeller's installation losses.

**A consistency item that is not resolved.** The design file still carries
`engine_displacement_cc: 250`, tagged `report-§2`, alongside a 10.849 kW rating. At
`argus7.prop.engine`'s assumed 7,500 rpm power peak that is a BMEP of **6.94 bar**,
against v1.0's 10.88 bar for the same displacement at 17 kW. Either this is a 250 cc
engine run well below its rating, or the displacement should have moved with the power
and did not. **The displacement field was inherited, not re-derived** — the same
inheritance defect §4.5 documents on the propeller, still standing.

### 4.3 The part-load BSFC curve

`argus7/prop/engine.py` implements a **Willans line** — fuel power affine in brake
power, because fuel buys *indicated* work and a nearly load-independent loss is
subtracted from it:

    BSFC(P) = k · (1 + P_loss(n) / P)

with loss power scaling as n·(F₀ + (1−F₀)·n/n_rated), near-quadratic in speed as
measured FMEP data are. The asymptote k is calibrated so that BSFC at 75% load and
rated speed equals the report's 270 g/kWh, giving **217.7 g/kWh** — 38% indicated
thermal efficiency, plausible for a modern SI engine and the check that the
calibration has not been pushed into fantasy.

At v5.0's mid-burn shaft power (3.214 kW) this returns **350.1 g/kWh**.

The optimiser uses a simpler fit to the same curve,
BSFC(load) = BSFC_full · (0.8471 + 0.1529/load), which at the recorded 29.98% load and
a 250.0 g/kWh full-load basis returns **339.3 g/kWh** (`opt_runs/layout_final.json`,
`bsfc_eff`). **The two independent implementations agree to 3.2%.** The gauntlet
audit's third, independently coded Willans line agreed with the module to 2.4% on a
different design point. This is one of the better-corroborated numbers in the report.

The same deck, run across the burn, gives 307.3 g/kWh at full fuel (43.7% load) and
**436.5 g/kWh dry (17.9% load)** — which is why freezing BSFC at the mid-burn value is
worth −6.6 h (§7.3).

**Five things about it that are assumptions or inconsistencies, and the report will
not hide them:**

1. **The load fraction at which 270 g/kWh is taken to hold is 0.75, and it is the most
   load-bearing unsourced number in the engine deck.** The report never says at what
   load its 270 holds. `engine.py`'s own comment sweeps it: 0.50 → 292.9 g/kWh (the
   report's >300 walk-away does **not** fire), 0.60 → 306.5 (fires), 0.75 → 321.3
   (fires, as coded), 0.90 → 332.0. **0.50 is not an absurd alternative reading.**
2. **The module contradicts itself on the friction fraction and refuses to resolve it.**
   `FRICTION_POWER_FRACTION_AT_RATED = 0.18` and the Gagg-Farrar altitude lapse's
   1/7.55 = 0.1325 are the *same physical quantity* and disagree by 36%. The file says
   so in terms and leaves both standing, because choosing between them is a modelling
   decision with a headline consequence. It is still unresolved.
3. **Throttling losses are folded in at a load-independent level.** A throttled SI
   engine's pumping loss grows as load falls, so the true deep-part-load penalty is
   **worse** than modelled. This model is the optimistic bound.
4. **BSFC was frozen at the mid-burn load in the mission integration.** See §7.3 — this
   is worth −6.6 h on v5.0.
5. **The load fraction the BSFC is read at was computed with a different propeller
   efficiency from the one the mission was flown with, and this is still an
   inconsistency in the recorded design point.** `scripts/run_optimisation_layout.py`
   sets the mid-burn shaft power with `argus7.opt.coupled.PROP_ETA = 0.84` and then
   integrates the mission at `prop_efficiency = 0.858`, while the design file records
   the propeller's own loiter efficiency as **0.8529**. Made self-consistent at 0.8529
   the mid-burn load is **29.62%**, not 29.98%, the effective BSFC is **340.8 g/kWh**,
   not 339.3, and the endurance is **165.80 h**, not 167.32 — **−1.53 h**. Small in
   magnitude; it is a constant used at a point it was not evaluated for, which is the
   exact failure class this report exists to stop repeating, and **it is the same
   finding this report made against v3.0 and it has not been fixed.** It needs an
   optimiser re-run, not an edit.

### 4.4 The BSFC that the answer actually rests on

The optimiser treated full-load BSFC as a variable bounded [0.250, 0.320] kg/kWh and
took **0.250 — the floor**. That is the report's own §6 language: *"BSFC is not
published — must be dyno-mapped; design assumes 270 g/kWh, target ≤250."*

**250 g/kWh is the target, not a unit.** The only two engines on v1.0 §6's shortlist
carrying a BSFC figure at all — the RCV DF70LC (*"verified 330 g/kWh"*) and the Orbital
HFDI-150 (*"~330 g/kWh"*) — are both **330 g/kWh**; the primary candidate, the Honda
250-class conversion the design actually assumes, has no published figure of any kind.
Endurance is exactly inversely proportional to BSFC in this model (BSFC enters mass
flow linearly and nothing else), so:

| Full-load BSFC | Effective at 30.0% load | Endurance |
|---|---|---|
| **250 g/kWh (as optimised — the §6 target)** | **339.3** | **166.56 h — 6.94 d** |
| 270 g/kWh (the §6 assumption) | 366.4 | 154.22 h — 6.43 d |
| 300 g/kWh (the §6 walk-away) | 407.1 | 138.80 h — 5.78 d |
| **330 g/kWh (the verified units)** | **447.8** | **126.18 h — 5.26 d** |

**This single row is the largest uncertainty in the report.** It is not an aerodynamic
question and it cannot be closed by analysis. It is closed by putting an engine on a
dyno.

Note also that the variable sits **on its bound**. An optimiser that takes the floor of
a procurement variable is telling you the answer is limited by procurement, not by
design — and v5.0's takes the floor exactly, where v3.0's took 0.2519, marginally
inside.

### 4.5 The propeller — a defect found, and fixed

**v3.0 and v4.0 were both first written with v2.0's propeller.** The cause is
structural and still present in the repository: `scripts/prop_design_sweep.py` and
`scripts/prop_refine.py` both **load `design/argus7_v2.yaml`** and both **hardcode
v1.0's boom station** (`BOOM = 0.6206 − 0.045`). Neither takes a design path. Anyone
re-running them gets a propeller for a 248 kg aircraft with an 8.15 kW engine at
4,191 m, regardless of which aircraft they meant.

The consequence, measured with `argus7.prop.bemt` at each aircraft's own mid-burn
loiter condition:

| Design point | Level-flight thrust required, mid-burn | The inherited v2.0 disc at 1,900 rpm delivers | Shortfall |
|---|---|---|---|
| **v3.0** as committed | 78.2 N | **58.1 N** | **−25.8%** |
| v4.0, before its propeller was re-solved | 76.0 N | 61.4 N | **−19.1%** |
| v5.0, had it inherited | 76.4 N | 60.1 N | −21.3% |

**v3.0 as published in the previous revision of this report could not hold level
flight at its own loiter point.** That is the defect, stated plainly rather than
absorbed. v4.0's design file records the fix in its own header comment; v5.0 carries it
forward.

**The v5.0 propeller, solved at v5.0's operating point:**

| | v3.0 (inherited) | **v5.0 (solved here)** |
|---|---|---|
| Diameter / blades / p/D | 1.04 m / 2 / 0.95 | **1.04 m / 2 / 0.95** |
| Loiter rpm | 1,900 (wrong for the aircraft) | **2,050** |
| Reduction ratio | 3.947 : 1 | **3.659 : 1** for a 7,500 rpm engine |
| Loiter efficiency at that rpm | 0.8581 (v2.0's) | **0.8530** |
| Climb power absorbed | 101.3% at 2,675 rpm | **101.2% of 10.849 kW at 2,675 prop rpm** |
| Tip Mach at loiter | 0.306 | **0.329** (against a 0.75 limit) |
| **Boom clearance** | 190 mm | **229 mm** |

At 2,050 rpm the disc makes **84.1 N against the 76.4 N** required at mid-burn — a 10%
margin — and the crank sits at **2,050 × 3.659 = 7,501 rpm**, on the assumed rating
rather than 7% above it as v3.0's gearing implied. The propulsion set closes at the
loiter design point.

**Variable pitch is not needed for the loiter mission — a genuine save.** The
loiter-optimal pitch is the same p/D the fixed-pitch optimum already uses, so a
constant-speed unit buys **+0.00%** at loiter. It would add mass, cost and a failure
mode to a 167-hour unattended flight for no endurance. **This conclusion does not
survive §8.4**, where the ferry mission wants a propeller this one cannot be.

**Three things about the propeller record that are still open:**

**(a) No committed script produces the v5.0 propeller.** `prop_design_sweep.py` and
`prop_refine.py` still load v2.0 and still hardcode v1.0's boom station. The v5.0
entries in the design file were solved interactively and reproduced here from
`argus7.prop.bemt` directly. **The propeller is verified but not regression-guarded**,
which is the same status as everything else in §11.5.

**(b) The rpm the design file records is the mid-burn rpm, not a fixed property.** A
fixed-pitch propeller on a throttled engine changes rpm with load. Across the burn the
disc needs **2,340 rpm at full fuel, 2,005 at mid, 1,600 dry**. At full fuel that is a
crank speed of **8,562 rpm — 114% of the assumed 7,500 rpm rating**, just inside the
engine module's own 1.15× overspeed limit and outside the speed at which its power
peak, and therefore its BSFC map, was defined. **The BSFC used for the first third of
the mission is read at a crank speed the engine deck does not cover.** Not quantified;
it is the next thing the engine deck should be asked.

**(c) `docs/decisions/2026-08-21-propeller-selection.md` describes a different
propeller on a different aircraft.** It selects 1.00 m at p/D 1.05 and 1,900 rpm,
preferring it over the 1.04 m disc because the larger one *"leaves only 56 mm to the
booms."* That 56 mm is computed from **v1.0's** boom station. On v5.0 the booms sit at
y = ±0.7943 m and the true clearance for a 1.04 m disc is **229 mm** — four times the
figure that drove the recommendation. **The record is superseded by the design file
and by this section**, and it should be marked as such.

---

## 5. Stability and control

This is where v1.0 fails hardest, and it is where v5.0 makes the change that v3.0 could
not.

### 5.1 Why v1.0 was divergent

Until `argus7/analysis/balance.py` was written, **nothing in the repository could
compute a CG, a neutral point, or a static margin** — while the report published
"+14.7% MAC at CG 42%" and `research/design_pack.md` published "neutral point 55% MAC,
static margin 10%". Two research packs
(`research/configuration_hypotheses.md` §3, `research/empennage_trade.md` open question
8) had already recorded from hand build-ups that the aircraft *"does not balance"*, and
it was never followed up in code. The retired v2.0 then grew the wing 40% with nothing
checking.

Measured on `design/argus7_v1.yaml` at its committed wing station (`x_le_frac` 0.22,
root LE at x = 0.748 m):

| | v1.0 |
|---|---|
| Neutral point, analytic (wing + tail) | 52.95% MAC |
| Neutral point, **AVL, independently** | **58.30% MAC** |
| CG, full fuel | **97.0% MAC** |
| CG, dry | **135.1% MAC** |
| **Static margin, full → dry** | **−44.0% → −82.2% MAC** |
| Static-margin excursion over the burn | **−38.15% MAC** |

The CG sits **194 mm aft of the neutral point at full fuel and 363 mm aft of it dry.**
This is not a marginal aeroplane; it is a divergent one, for the whole flight.

**Crucially, this is not a modelling artefact.** The **neutral-point half of the
published stability line reproduces**: 52.95% analytic and 58.30% from the vendored
AVL bracket the published ~55% MAC. It is the **CG half** that does not exist. The
report's 42% MAC CG is an assumed target that no mass build-up on the committed
geometry supports. It cannot be recovered by tuning the equipment layout either:
moving **all 63 kg** of payload, avionics and recovery to the nose at x = 0 still
leaves v1.0's CG at 72% MAC. It is the **wing station**, and `x_le_frac = 0.22` was
tagged `assumption` and sourced to nothing.

`research/design_pack.md`'s claim that fuel tanks at the AC hold CG travel under 0.5%
MAC fails by **76×** on v1.0. The *mechanism* is sound — fuel at the CG moves the CG
not at all — but it is conditional on the CG being where the report assumes. The fuel
centroid is at 41.2% MAC, close to the claimed 45%; the CG is at 97.0%.

All of the above is asserted by strict `xfail` tests in `tests/test_balance.py` that
carry the measured numbers in their reason text and will **error** the moment anyone
makes them pass without rewriting the reason.

### 5.2 The v5.0 neutral point

    Xnp/MAC = Xac_wing/MAC + V_h · (a_t/a_w) · (1 − dε/dα) · η_t

| Term | v3.0 | **v5.0** |
|---|---|---|
| Wing AC | 25% MAC (thin-airfoil; see the bias note below) | 25% MAC |
| V_h | 0.4218 | **0.6018** |
| a_w (Helmbold/DATCOM) | 5.724 /rad (AR 21.44) | **5.790 /rad** (AR 24.57) |
| a_t (panel AR 3.0) | 3.335 /rad | 3.335 /rad |
| dε/dα = 2a_w/(πAR) | 0.1700 | **0.1500** |
| η_t (tail dynamic-pressure ratio) | 1.00 | 1.00 — the inverted V sits on booms outboard of the fuselage wake and ahead of the pusher disc |
| **Tail contribution** | +20.40% MAC | **+29.46% MAC** |
| **Neutral point, analytic** | 45.40% MAC | **54.46% MAC** (x = 1.7212 m) |
| **Neutral point, AVL (wing + inverted-V tail, real dihedral)** | 50.98% MAC | **59.70% MAC** (x = 1.7495 m) |
| Munk fuselage apparent-mass term | −4.47% MAC | **−4.49% MAC** |

The tail contribution has grown by half, and it is bought with **arm**, not area: S_h
fell 13% while the arm grew 61%. That is the efficient direction — arm costs boom mass
and boom drag, area costs both plus tail mass — but it is also what put a 6.25 m
cantilever on the aircraft (§6.6).

### 5.3 CG, static margin and fuel burn

| Fuel state | Mass (kg) | x_cg (m) | CG (% MAC) | SM (% MAC) | SM with Munk pod (% MAC) |
|---|---|---|---|---|---|
| Full | 320.00 | 1.6524 | 41.74 | **+12.72** | +8.23 |
| Half | 233.79 | 1.6508 | 41.44 | +13.02 | +8.53 |
| Dry | 147.58 | 1.6473 | 40.79 | **+13.68** | +9.18 |

**Static-margin excursion full → empty: +0.95% MAC**, and it moves in the *safe*
direction — the aircraft gets more stable as it burns fuel, not less.

This is the finding that justifies putting the layout in the optimiser. **The design
pack's "<0.5% MAC CG travel" claim, which failed by 76× on v1.0, is very nearly
achieved here** — 0.95% against a claimed 0.5%, and achieved *for the reason the pack
gave*, not by accident. The fuel centroid sits at **42.55% MAC**, 95 mm aft of the wing
AC and within **0.8% MAC of the CG itself**, so 172.4 kg — 54% of gross mass — burns
off while moving the balance by less than 1% of chord.

Note that v3.0 did better on this one metric (−0.08% MAC), and v5.0 is not worse for
it: v3.0 bought its near-zero travel at a static margin that failed the gate. **A
+0.95% travel inside an 8–20% window is a better aeroplane than a −0.08% travel below
the floor.**

Moving the wing station from 0.22 to 0.4075 is what does it. It moves the neutral
point aft nearly 1:1 while moving only the wing group and the wing fuel with it, so
static margin rises monotonically with `x_le_frac` — and it simultaneously puts the
tanks where the CG lands.

### 5.4 The honest band, and the two biases that partly cancel

**The static margin depends on which neutral point you believe, and the spread is
wide.** On v3.0 that spread straddled the gate. On v5.0 it does not.

| Reading | Neutral point | SM, full fuel | SM, dry | 8–20% MAC gate |
|---|---|---|---|---|
| Analytic, wing + tail (the convention the spec and the published 55% figure are written in) | 54.46% MAC | **+12.72%** | **+13.68%** | ✅ |
| Analytic + Munk fuselage term | 49.97% MAC | **+8.23%** | +9.18% | ✅ (by 0.23 points) |
| **AVL, wing + tail** | **59.70% MAC** | **+17.96%** | +18.91% | ✅ |
| AVL + Munk fuselage term | 55.20% MAC | **+13.46%** | +14.41% | ✅ |
| The batched model the optimiser searched with | — | +19.92% | +16.91% | (search only) |

**All four readings clear the floor at both fuel states, and all four sit under the
ceiling.** That sentence could not be written about any previous design point in this
programme. The tightest reading — analytic plus the Munk pod term — clears 8% by
0.23 points at full fuel, which is thin; the widest — AVL without the pod — reaches
18.91% dry, 1.1 points under the ceiling. **The design is inside the window on the
pessimistic reading and inside it on the optimistic one**, and the gate is met without
having to argue about which convention is right.

**Two known method biases run in opposite directions and are declared, not netted:**

1. **The 25% wing AC is conservative.** Running the AVL deck with the tail surface
   deleted puts the isolated wing's AC at **30.2–30.5% MAC** on a planform with sweep,
   taper and twist — 5.2 to 5.5% MAC aft of the quarter-chord. Every static margin
   computed with 0.25 is therefore **understated by about 5% MAC**. That difference,
   not any tail effect, is most of the gap between the analytic and AVL neutral points.
2. **The Munk pod term is not in the headline number and it is worth −4.49% MAC.** It
   is excluded because the specification's relation and the published 55% MAC figure
   are both wing-plus-tail only, and because AVL — the independent check — carries no
   fuselage. It is Munk's apparent-mass estimate, which
   `research/configuration_hypotheses.md` §3.3(a) computes for this pod as 8.2% on
   v1.0 against 7.3% by the more elaborate Multhopp strip method: **this term is the
   pessimistic end of the published band.**

Applied together (AVL wing AC + Munk pod) the answer is **+13.46% MAC** — almost
exactly the middle of the spec window.

**One thing that is not in this analysis at all:** dynamic stability, control power,
trim authority, spiral and Dutch-roll modes, aeroelastic trim, and departure
behaviour. This is a longitudinal static balance and nothing more. On a wing that
deflects 14.4% of semi-span at limit load (§6.2) and carries a 6.25 m boom-mounted
tail, the aeroelastic trim question in particular is not academic.

### 5.5 The gate v3.0 did not pass, and how it was closed

Recorded here because the mechanism matters more than the outcome.

The programme's pre-registered static-margin gate is
**8% ≤ SM ≤ 20% MAC** — `docs/superpowers/specs/2026-08-20-argus7-cad-sim-optimisation-design.md`
line 109, and line 178 makes *"no regression on static margin validity"* a conjunctive
adoption gate.

**The optimiser that produced v3.0 searched a 5–15% window instead.** The v3.0 design
file's own header records it. Nothing in `docs/decisions/` records a ruling that moved
8–20% to 5–15%. v3.0 landed at **+5.79%** and duly failed the real gate — which is
exactly what `docs/decisions/2026-08-20-gauntlet-preregistration.md` exists to prevent,
and which §11.3 of this report condemns in the abstract.

**How it was closed, and the closure carries its own caveat.**
`scripts/run_optimisation_layout.py` now carries `SM_LO, SM_HI = 0.08 + 0.047,
0.20 + 0.047`. The `+0.047` is a deliberate offset, and the script says why in a
comment: **the batched balance model used inside the search reads about 4.7% MAC high
against the authoritative `argus7.analysis.balance`** — it returned 10.5% where the
scalar module measured 5.79% on v3.0. Biasing the search window compensates for a known
model disagreement so the search lands where the authoritative module will confirm it.

That is a defensible engineering move and it worked: v5.0's search value is 19.92% and
its verified value is 12.72%, a 7.2-point gap in the expected direction, landing
comfortably inside the real window. **But it is a magic number tuned on one comparison,
it is 53% larger than the discrepancy it was fitted to, and the honest description is
"search with the biased model, verify with the authoritative one" — which is what was
done.** The verification is what this report publishes; the search value appears
nowhere in §5.3.

---

## 6. Structures

**This section is new.** The previous revision of this report opened §6 with *"The
structural work in this repository is research-grade, not design-grade: no FEA, no test
coupons, no article."* CalculiX and gmsh had been installed since day one and never
pointed at the airframe; `docs/argus7_v3_premortem.md` mode #7 — *"the wing that was
never analysed"* — scored the highest impact on the page and the worst detection
profile, precisely because nothing existed to detect anything with.

`scripts/structural_analysis.py` and `docs/decisions/2026-08-21-structural-analysis.md`
are the first structural analysis in the programme. **It does not clear mode #7. It
confirms the concern and adds a specific, quantified defect to the mass model.**

### 6.0 What is trustworthy here, and what is not — read this first

| Result | Method | Status |
|---|---|---|
| Tip deflection 14.4% of semi-span at limit | analytic M/EI double integration over the tapered spar | **Cross-validated** — `research/materials_pack.md` independently gives 14.2% |
| Root cap stress 600 MPa at ultimate | closed form on the mass model's own sizing | **Trustworthy, and circular** — this is how the mass model sizes, so a zero margin is a tautology, not a result |
| Cap buckling critical at 80 MPa | plate/column buckling between ribs | **Sign trustworthy, magnitude uncertain** — corroborated independently by the cap's b/t ratio, §6.3 |
| Divergence ~1,030 km/h, flutter ~493 km/h | first-order torsional divergence and a binary flutter approximation | **Directionally trustworthy** — a 2.4× margin is robust to a crude method |
| Boom first torsion 14.5 Hz | Bredt closed-cell torsion on the derived boom length | Trustworthy at the level of a hand calculation; **supersedes** the research pack's 22.7 Hz |
| **CalculiX beam FEA — deflections and mode shapes** | B31 Timoshenko beams, section converted to an equivalent rectangle | **NOT TRUSTWORTHY. Its numbers are not used anywhere in this report and should not be quoted.** |

**On the FEA, plainly.** The beam model does not reproduce the cross-validated
deflection. The fault is in the section definition: section properties are converted to
an equivalent rectangle, and CalculiX's local-axis convention means the bending
direction and the section's strong axis are not reliably aligned. One bug in that
conversion (b and h transposed, worth a factor of 10⁴ in second moment of area) was
found and fixed; the conversion has since been revised again, and **the model's tip
deflection has moved by more than an order of magnitude across those revisions within a
single working day, without ever landing on the cross-validated 14.4%.** A model whose
answer moves that far when the person editing it changes their mind about an
orientation vector is not measuring the wing.

The modal frequencies come from the same model and inherit the same doubt. **They are
deliberately not reproduced in this report.** The one modal number quoted anywhere here
— the boom's 14.5 Hz first torsion — is an analytic Bredt calculation, not a CalculiX
output.

**What would settle it:** define the section explicitly with
`*BEAM SECTION, SECTION=GENERAL`, giving A, I11, I12, I22 and J directly rather than via
an equivalent rectangle, and validate against a uniform cantilever with a closed-form
solution *before* trusting any tapered result. Until that is done the FEA contributes
nothing and the analytic routes carry the section.

### 6.1 The load case and the spar

`argus7.opt.design_space` sizes the spar cap from root bending moment:

    M_root = n_ult · W · (b/2) · k_lift · fuel_relief
    A_cap  = M_root / (h_spar · σ_cap),  h_spar = (t/c) · c_root
    m_cap  ∝ ρ · A_cap · (b/2) · k_taper

with n_ult = 5.7, k_lift = 0.40, fuel relief 0.78, σ_cap = 600 MPa (compression
allowable, nominally carrying a buckling/damage knockdown), ρ = 1600 kg/m³.
Substituting gives **m_cap ∝ W · AR^1.5 · √S / (t/c)** — the exponent verified
analytically by the gauntlet audit, and the wing-mass *ratio* between two design points
agreed with Raymer's independent GA regression to 1.0%.

| | v1.0 | v3.0 | **v5.0** |
|---|---|---|---|
| Root chord | 0.5807 m | 0.6192 m | **0.7720 m** |
| **Spar depth at root** | 79.6 mm | 118.2 mm | **169.8 mm** |
| Ultimate root bending moment | 20.19 kN·m | 30.74 kN·m | **33.08 kN·m** |
| **Required cap area** | 423 mm² | 433 mm² | **325 mm²** |
| Cap mass | 14.56 kg | 18.16 kg | **14.31 kg** |
| Skin / rib / systems (4.6 kg/m²) | 17.94 kg | 27.23 kg | **26.31 kg** |
| **Wing total** | **32.51 kg (8.33 kg/m²)** | **45.39 kg (7.67 kg/m²)** | **40.63 kg (7.10 kg/m²)** |

**The interesting row is the cap area: 325 mm² against v1.0's 423 mm², despite +28%
MTOW and +28% span.** Thickening the section from 13.7% to 22.0% makes the spar 113%
deeper, and depth buys cap area back faster than weight and span consume it. That is
the mechanism by which a much larger wing costs only +8.1 kg over v1.0's and is
*lighter* than v3.0's.

**Areal density cross-check, and it has crossed to the wrong side.** 40.63 kg on
5.7201 m² is **7.10 kg/m²**. The materials pack's costed build options, computed from
first principles: Option A (moulded CFRP sandwich, female moulds) 6.85 kg/m²,
Option B (pultruded strip caps + moulded sandwich skin, the recommendation)
**7.40 kg/m²**, Option C3 8.65 kg/m². **v3.0's wing sat 3.6% above the recommended
build. v5.0's sits 4.0% below it.** That is not evidence of a lighter wing; it is the
mass model returning a number the recommended build does not reach, and it is the same
direction as §6.3's finding.

### 6.2 The wing is very flexible, and that is cross-validated

Two independent routes agree:

| Route | Tip deflection at limit (+3.8 g) |
|---|---|
| M/EI double integration over the tapered spar (`scripts/structural_analysis.py`) | **14.43% of semi-span** |
| `research/materials_pack.md`, independently derived | **14.2%** |

**Agreement to 0.2 points across separately-derived methods. 855 mm of tip rise at
limit load on a 5.93 m semi-span**, and **1,283 mm — 21.6% — at ultimate**, far enough
into geometric non-linearity that a linear beam calculation stops being trustworthy at
the ultimate case. Modern 15 m sailplanes run 8–10%. **This is a sailplane wing, not a
light-aircraft wing.**

It is not obviously disqualifying, and it should not be presented as if it were. It is
also not free:

- **It inverts the material argument.** The figure of merit for a stiffness-critical
  wing is E/ρ, not σ/ρ. Pultruded rod's 1,682 MPa compressive strength buys nothing
  here; high-modulus pultrusion (+71% EI at equal mass) is the right lever, and it is a
  procurement decision, not a layup one.
- **It interacts with the span efficiency the endurance rests on.** The AVL sweep
  measured e on an undeflected planform. An 855 mm tip rise changes the spanload, the
  dihedral effect and the effective aspect ratio. Nothing in this stack couples them.
- **It interacts with control effectiveness and with flutter.** §6.4 says the flutter
  margin is large; that estimate is made on an undeflected wing.

For comparison, v3.0's wing was **15.3%** at limit on the same method — marginally
worse. This is one of the few structural quantities where v5.0's deeper section helps.

### 6.3 Buckling governs the sizing, and the margin is negative

The cap reaches its 600 MPa material allowable exactly at ultimate — zero margin **by
construction**, because that is how the mass model sizes it. That row is a tautology.

The row that is not a tautology is local buckling of the compression cap between ribs:

| | Value |
|---|---|
| Cap section, as assumed by the analysis | 36.0 × 9.01 mm |
| Rib pitch | 350 mm (assumed) |
| **Critical stress** | **80.2 MPa** |
| Applied stress at ultimate | 600 MPa |
| **Margin** | **−86.6%** |

**The cap would buckle at roughly an eighth of the load the material could carry.**

**An independent corroboration, from a completely different route.** The gauntlet audit
condemned the original challenger's cap laminate on a width-to-thickness argument:
1.10 mm thick at b/t ≈ 200 is *"not entitled to a 600 MPa allowable already carrying a
buckling knockdown."* Applying the same test at a 0.25c cap width:

| | v1.0 (the calibration point) | v3.0 | **v5.0** |
|---|---|---|---|
| Cap width × thickness | 145 × 2.91 mm | 155 × 2.80 mm | **193 × 1.68 mm** |
| **b/t** | **50** | **55** | **115** |

**v3.0 sat essentially where the calibration point does. v5.0 sits at more than twice
that slenderness**, because a 170 mm-deep spar needs only 325 mm² of cap and spreading
325 mm² over a 193 mm width leaves a 1.68 mm laminate. The previous revision of this
report was able to write *"the buckling concern raised by the audit does not bite
here."* **On v5.0 it bites.** Two independent methods — an explicit buckling
calculation and the audit's b/t heuristic — say the same thing, and they were not
calibrated against each other.

**What this changes, and it is not a caveat:**

- **The mass model is optimistic.** A buckling-sized cap is heavier than a
  strength-sized one. The mass model uses the latter, so wing mass is understated by an
  amount nobody has computed.
- **Wing mass converts to endurance at 1.51 h/kg** (§6.5). This is therefore an
  endurance correction of unknown size and known sign.
- **The fix is not more carbon.** It is rib pitch, cap width-to-thickness ratio and
  skin support — a design task. A narrower, thicker cap at the same area buckles at a
  higher stress for no mass; closer ribs cost a little mass and buy a lot of critical
  stress. Both are available. Neither has been done.
- **σ_cap = 600 MPa is applied without a minimum-gauge or panel-buckling floor**, which
  was already a declared model limit. v5.0 is the first design point that stands on it.

**The honest caveat, from the analysis's own record:** the cap cross-section aspect
ratio in the buckling calculation is assumed, not designed, and the rib pitch is
assumed. **The magnitude of the shortfall is uncertain; its sign is not**, and the b/t
cross-check makes the sign independent of the assumption.

### 6.4 Aeroelastic — the good news, and it retires a real worry

| | Value |
|---|---|
| Root GJ | 202 kN·m² |
| **Divergence speed** | **~1,030 km/h TAS** |
| Wing first torsion | ~34 Hz |
| **Flutter estimate** | **~493 km/h TAS** |
| Power-limited maximum level speed (§8.3) | **207 km/h** |

**Both aeroelastic speeds are far above the power limit, so the aircraft is
power-limited rather than aeroelastically limited.** That retires the concern raised
when the speed envelope was first computed: a high-aspect wing on slender booms might
have capped V_max below its power limit. It does not — the flutter margin is 2.4×.

**These are first-order estimates** — torsional divergence and a binary flutter
approximation, not a coupled aeroelastic solution — and the flutter estimate uses an
assumed wing torsional mass (half of 60% of the airframe mass, 20.6 kg, against an
actual wing mass of 40.63 kg) and an assumed radius of gyration of 0.25 MAC. The margin
is large enough that the *conclusion* survives the method being crude; the *number*
should not be quoted to three figures, and this report does not.

For scale: v3.0's same calculation gave divergence at 721 km/h and flutter at 352 km/h
— still above its power limit, but v5.0's deeper, stiffer section roughly doubles GJ
and buys a 40% higher flutter speed for free.

### 6.5 The mass-to-endurance exchange rate

**Measured on this design point: 1.51 h/kg** (removing 1 kg of fuel at constant MTOW
costs 1.511 h). The materials pack independently derived 1.5 h/kg on v1.0; the previous
revision measured 1.41 h/kg on v3.0. Every structural decision can be priced with it,
and every one of §6's open items is a mass item.

### 6.6 The booms, and why the research pack no longer describes them

`research/boom_construction_pack.md` sizes the booms to a **stiffness** criterion
(1.5° of tail rotation), not a strength one, and corrects the tail load upward by
1.81× from the materials pack's figure. **Every number in it was computed for a 3.646 m
boom carrying a 0.31 m² tail behind a 0.813 m propeller at 2,100 rpm. v5.0 has a
6.25 m boom carrying a 0.32 m² tail behind a 1.04 m propeller at 2,050 rpm.** The boom
is **71% longer** than the one the pack sized, and boom bending stiffness requirements
scale with the cube of length.

What survives, what has moved, and what has not been re-run:

- **Re-run for v5.0, and it moved: first torsional frequency is 14.5 Hz**, against the
  pack's 22.7 Hz for the 3.65 m boom. Propeller 1P is at 34.2 Hz and blade passage at
  68.3 Hz, so the nearest separation is **19.7 Hz** and the mode is clear. This is the
  one boom number that has been re-derived at this design point, and it is *better*
  separated than the pack's was, because the longer boom moved the mode down and away
  from 1P rather than into it. `docs/decisions/2026-08-21-structural-analysis.md`
  records this as superseding the pack.
- **Not re-run, and the pack's recommendation is now certainly wrong:** the stiffness
  sizing. The pack recommends COTS roll-wrapped **110 mm × 2.0 mm, 7.54 kg for the
  pair** (9.20 kg with fittings) for a 3.646 m boom. The design file still specifies
  **Ø90 mm**, which met the pack's requirement only at 10.06 kg on the short boom. **On
  a 6.25 m boom neither figure applies**, and the tail rotation criterion has not been
  evaluated. The 28 kg fixed non-wing airframe mass (§2.2) is carrying this.
- **The propwash premise is geometrically false, and that is the good news.** The booms
  clear the propeller tip path by **229 mm** on v5.0 (§4.5) and sit in the acoustic near
  field at ~10–30 Pa, not in the wake at 300–560 Pa — a 20–40× difference in
  excitation. Forced-response on v1.0's geometry gave a peak vibratory strain of
  **0.011% against a 0.6% matrix fatigue limit: a 55× margin.** The clearance argument
  strengthens with every design point because `booms.y_station_frac` is a fraction of
  semi-span; the forced-response number has not been re-run.
- **Three configuration prohibitions follow and are unchanged:** nothing structural
  inside r = 0.45 m of the thrust axis aft of the prop plane; the first torsional mode
  must be resolved against the true loiter rpm (now done, 14.5 Hz vs 34.2 Hz); and
  **measure it** — one tap test with the tail fitted settles the section in an
  afternoon.
- **The tail attachment as proposed has a negative margin before fatigue**: two M6 at
  60 mm centres carrying the panel root moment gives 306 MPa of bearing against a
  165 ± 28 MPa allowable. A Ø50 × 150 mm spigot gives 1.76 MPa. **Zero mass, zero drag,
  a factor of 174 on the margin.** This is the cheapest fix in the programme and it is
  still not in the design.

### 6.7 What the materials research establishes

The sponsor's premise — *"carbon fibre rods and tubes and 3D printed parts as much as
possible"* — was evaluated and is **right about spar caps and booms, wrong about the
wing spar and the skins, roughly break-even on ribs.**

| Claim | Verdict | The number |
|---|---|---|
| Pultruded UD carbon as spar-cap material | **Right, strongly** | 1,682 MPa compressive / 133.8 GPa measured, two independent vendors agreeing. E/ρ **87.9 vs 77.8** for hand wet layup — it matches prepreg on specific stiffness with no autoclave, no freezer, and no layup skill |
| COTS carbon tube for the twin booms | **Right** | 90 × 2.5 mm roll-wrapped runs at 102 MPa against a 620 MPa allowable — **4× strength margin**, stiffness-critical. **Computed for a 3.646 m boom; v5.0's is 6.25 m and this has not been re-run** |
| COTS carbon tube as the **wing** spar | **Wrong, by a clean geometric factor** | A round tube inside a 12%-thick wing needs **2.07×** the material of a cap-and-web spar for the same moment. The ratio is 2h/D — pure geometry, not a materials argument |
| 3D-printed ribs, fairings, trays, ducts | **Acceptable at a 3.8–4.4× mass penalty** | Rib stress **0.06 MPa, 170× below the creep-test floor**. This is where the preference is simply free — **but see §6.3: rib pitch is now a structural variable, not a free one, and printed ribs in a wet-wing tank bay also have to seal** |
| Printed skin panels | **Wrong, decisively** | ±1.14 mm MJF tolerance against a 0.512 mm step budget; **+18.7 kg**, 46% of v5.0's entire wing budget |
| Heat-shrink film skin | **Wrong, but not for the usual reason** | Streamwise waviness actually passes. It fails because film cannot form the leading edge, and its scalloping is a **spanwise** disturbance for which NASA states no criteria exist |
| Printed tooling, plugs, jigs | **Right, and under-used** | The highest-leverage use of printing on the programme — it attacks the €9–14k wing-tooling quote that is the premortem's highest-probability failure mode |

**And the surface-quality bar is about 6× looser than the programme assumed.**
Carmichael's allowable single-wave h/λ at Re 0.6–1.1 M is 0.031–0.044, because
allowable waviness scales as Re^−0.75. NASA TP-2256 **measured** moldless homebuilt
VariEze/Long-EZ wings at h/λ 0.0030–0.0046 — passing with 2.6–4.9× margin. **A garage
build can hold laminar flow.** Measured, not asserted. Note that v5.0's tip Reynolds
number is *lower* than the range that criterion was tabulated over, which makes the
allowable *looser* still, not tighter.

### 6.8 Recovery

Unchanged from v1.0 in mass (7.0 kg) and unchanged in the design file, but **the
aircraft got 28% heavier and the recovery system did not**.

| | v1.0 | v3.0 | **v5.0** |
|---|---|---|---|
| Recovery mass allowance | 7.0 kg | 7.0 kg | **7.0 kg (unchanged)** |
| Descent rate on v1.0's 85 m² canopy, at MTOW | 5.43 m/s | 6.07 m/s | **6.14 m/s** |
| Canopy area for 6 m/s at MTOW | 69.5 m² | 87.0 m² | **89.0 m²** |
| Touchdown energy at 6 m/s, dry recovery mass | 2.67 kJ | 2.74 kJ | **2.66 kJ** |
| Touchdown energy at 6 m/s, MTOW | 4.50 kJ | 5.63 kJ | **5.76 kJ** |

Recovery normally happens near dry mass, where v5.0 is essentially identical to v1.0
(2.66 vs 2.67 kJ) — the airbag/crush-keel case does not move, and v5.0's *dry* mass is
actually 1 kg lighter than v1.0's because it burns proportionally more fuel. **The MTOW
case does move**, and the ground-risk argument in v1.0 §9 was built on the 3–4.5 kJ
figure. The gauntlet audit's recommendation that recovery mass scale with MTOW
(7.0 → 8.96 kg at 320 kg) is not implemented.

---

## 7. Mission performance — endurance

### 7.1 How the 6.97 days is computed

`argus7.mission.sim.simulate_loiter` integrates a pure loiter until the fuel is gone,
in 120 equal-fuel-mass steps by the midpoint rule. Per step, at weight W:

    C_L      = min( √(3·C_D0·π·AR·e),  C_Lmax / 1.15² )     [stall-limited here]
    C_D      = C_D0 + C_L² / (π·AR·e)
    V        = √( 2W / (ρ·S·C_L) )
    D        = W / (L/D)
    P_shaft  = D·V / η_prop  +  P_elec / η_alt
    ṁ        = BSFC · P_shaft
    E        = Σ Δm / ṁ

with η_alt = 0.75, P_elec = 500 W, ρ from the ISA at 4,000 m, and BSFC = 339.3 g/kWh
(the part-load value at the mid-burn load fraction, §4.3).

Result at **η_prop = 0.858**, the value hardcoded in
`scripts/run_optimisation_layout.py`: **167.325 h = 6.9719 days**, reproducing
`opt_runs/layout_final.json` to 0.008%.

**Result at η_prop = 0.8529, the value `design/argus7_v5.yaml` records for its own
propeller: 166.562 h = 6.9401 days.** The report's headline is the first number
because that is what the optimiser recorded; **the second is the one the design file
supports**, and the gap is §4.3 item 5.

| | Full | Mid | Dry |
|---|---|---|---|
| Mass (kg) | 320.00 | 233.79 | 147.58 |
| TAS (km/h) | 119.8 | 102.4 | 81.4 |
| Drag (N) | 104.6 | 76.4 | 48.2 |
| Shaft power (kW) | 4.75 | 3.21 | 1.94 |
| Engine load fraction | 43.7% | 29.6% | 17.9% |
| Engine-deck BSFC at that power (g/kWh) | 307.3 | 350.1 | 436.5 |

### 7.2 The validation gates it passed

**Gate 1 — the step integration must reproduce the closed-form Breguet solution.**
Called with `payload_power_w = 0` and a constant BSFC — the conditions under which the
analytic solution exists — the 120-step integrator matches the Breguet form to better
than 0.001% on this design point's polar, and moving to 20,000 steps changes the answer
by a further 0.0007%, so the discretisation contributes nothing. The committed test,
`tests/test_mission_sim.py::test_gate1_step_integration_matches_closed_form_breguet`,
runs the same gate on **v1.0's** polar at 400 steps — 142.7478 h against 142.7478 h — at
a <0.1% threshold.

**Gate 2 — the same simulator must reproduce the published v1.0 endurance.** Run on
v1.0's published polar (S 3.9, AR 22, C_D0 0.020, e 0.85, MTOW 250, fuel 101.5,
4,000 m, BSFC 270, η_prop 0.84, 500 W payload), it returns **112.977 h against the
published 112.8 h: +0.16%.** Asserted by
`::test_gate2_reproduces_the_published_endurance`. The gauntlet audit's fully
independent re-implementation — its own ISA from the ICAO defining constants, its own
adaptive-quadrature Breguet integration — got **112.977 h** as well, and agreed with
the repository to **six significant figures** on the coupled model's own aero.

**This is worth stating precisely, because it is the trap this programme keeps
falling into: six figures of agreement means the arithmetic has been checked and
passed. It says nothing about the model.** The v1.0 number that reproduces to 0.16% is
a number for an aircraft that cannot balance, cannot hold its fuel, and cannot turn
its propeller.

### 7.3 Where the headline is optimistic, quantified

**BSFC was frozen at the mid-burn load and this costs 6.6 hours.** The optimiser
evaluates the part-load BSFC once, at the mid-point shaft power, and holds it constant
for the whole integration. But engine load falls from 43.7% to 17.9% across the burn,
and BSFC(load) goes as 1/load. By convexity the average of the true BSFC exceeds the
BSFC at the average load. Re-running the integration with BSFC evaluated **pointwise**
at each step's shaft power:

| | Endurance |
|---|---|
| BSFC frozen at mid-burn load, η 0.8529 | 166.56 h — 6.940 d |
| **BSFC evaluated pointwise across the burn** | **159.98 h — 6.666 d** |

**−6.58 h (−0.27 d).** This is a real, unreported optimism in the headline number, and
it is a property of the *evaluation*, not of the aircraft. It is 18% larger in absolute
terms than the same correction on v3.0, because v5.0 burns a larger fuel fraction and
therefore traverses more of the BSFC curve.

### 7.4 Sensitivity

#### v1.0's published anchors: two of the three are wrong

v1.0 §4 states: *"BSFC 250 g/kWh → +0.5 d; C_D0 0.016 → +0.36 d; loiter at 3,000 m
instead of 4,000 m → +0.23 d."* All three were re-derived by the gauntlet auditor from
first principles with independent code, and all three re-derived again with the
repository's own simulator on the published polar. Both derivations agree.

| Anchor | v1.0 published | **Measured** | Verdict |
|---|---|---|---|
| C_D0 0.020 → 0.016 | +0.36 d | **+0.358 d** (+8.588 h) | ✅ correct to 0.6% |
| BSFC 270 → 250 g/kWh | +0.5 d | **+0.377 d** (+9.038 h) | ❌ **the report is high by 33%** |
| 4,000 m → 3,000 m | +0.23 d | **+0.198 d** (+4.742 h) | ❌ **the report is high by 16%** |

**Two of the three published sensitivity anchors are wrong, and both errors are in the
optimistic direction.** Endurance is *exactly* inversely proportional to BSFC in this
model, so +0.5 d would require 244 g/kWh, not 250. The C_D0 anchor reproduces, which
corroborates `research/riblets_pack.md`'s appendix; the other two do not. Both are
levers the programme leans on.

#### v5.0's own sensitivities

Computed on the v5.0 design point at the design file's own η_prop 0.8529 and
bsfc_full 0.250 — **baseline 166.56 h (6.940 d)** — one lever at a time, everything else
held:

| Lever | Endurance | Δ |
|---|---|---|
| **Baseline** | **166.56 h — 6.940 d** | — |
| C_D0 −0.004 (an exceptionally clean build) | 180.29 h | **+0.572 d** |
| C_D0 +0.0035 (turret + cooling + base drag allowance) | 156.17 h | **−0.433 d** |
| Loiter at 3,000 m (band floor) | 173.31 h | **+0.281 d** — but coverage falls from 367 to 207 km², −44% |
| Loiter at 4,500 m (band ceiling) | 163.20 h | −0.140 d — coverage rises to 464 km², +27% |
| Payload duty-cycled to 350 W average | 179.16 h | **+0.525 d** |
| Oswald e 0.77 instead of 0.8101 (the open band, §3.4) | 162.79 h | −0.157 d |
| Full-load BSFC 270 instead of 250 | 154.22 h | −0.514 d |
| Full-load BSFC 330 (the verified units) | 126.18 h | **−1.682 d** |
| Non-wing mass charged honestly (−6.6 kg of fuel) | 156.77 h | **−0.408 d** |
| BSFC evaluated pointwise across the burn | 159.98 h | **−0.274 d** |

**The altitude row deserves its own sentence.** Going to the band ceiling costs
0.14 days and buys 27% more coverage area; going to the band floor buys 0.28 days and
gives up 44% of it. **Nothing in the objective function knows that coverage exists**,
which is why the optimiser sat on the floor of its altitude bound. On a
communications-relay aircraft that is an objective-function defect, not a design
choice, and it is the same defect that let the retired v2.0 fly below the band
entirely.

### 7.5 What is not modelled

Every endurance figure in this section is **pure loiter**. There is no transit segment,
no climb to altitude, no reserve, no descent, no hold, no diversion, and no wind. v1.0
published a deploy-mode table (2,000 km transit → 3.98 d on station); **nothing in
this repository can reproduce or replace that table**, and it should not be quoted.
§8 computes a straight-line ferry, which is a different mission, not a replacement.

The comms coverage figures in §1 are the v1.0 elevation-angle model rescaled to the
new altitude. No link budget, no antenna pattern, no measured data in this altitude
band.

---

## 8. Range and the speed envelope

**This section is new.** No previous revision of this report contained a range figure,
a cruise speed, a stall speed, or a maximum level speed. It is computed by
`scripts/range_analysis.py` from `design/argus7_v5.yaml` and the repository's own
models, and recorded in `opt_runs/range.json`.

### 8.1 Endurance and range are different missions at different speeds

This is the framing the section exists to establish, because conflating the two is how
a long-endurance aircraft acquires a range claim it cannot fly.

**Endurance maximises time aloft, so it flies at minimum *power*** — high lift
coefficient, slow. **Range maximises distance, so it flies at minimum *drag*** — the
best-L/D lift coefficient, faster. They are different flight conditions on the same
polar, and **you do not get both from one flight**.

| | Loiter mission | Ferry mission |
|---|---|---|
| **Time aloft** | **167.3 h (6.97 d)** | 131.8 h (5.49 d) |
| **Still-air distance** | not a useful quantity | **17,659 km** |
| Speed | ~102 km/h TAS (mean over the burn) | **134 km/h TAS** |
| Lift coefficient | 1.2098 (stall-limited) | ~1.03 (best L/D) |
| Governing quantity | C_L^1.5/C_D | L/D |

**L/D max is 30.42 at C_L 1.0281**; the loiter point sits at C_L 1.2098 where L/D is
30.02, so the loiter condition gives up only 1.3% of L/D — the polar is flat here, and
that is why the two missions are closer together than they would be on a conventional
aircraft.

### 8.2 The range result

| | Value |
|---|---|
| **Best still-air range** | **17,659 km at 134 km/h TAS** |
| Time aloft at that speed | 131.8 h = 5.49 d |
| Within 1% of best | **124–146 km/h** — a broad, flat optimum |
| Range at 120 km/h | 17,365 km (−1.7%) |
| Range at 200 km/h | 14,291 km (−19.1%), 71.5 h |
| Payload–range | 23,578 km at zero payload, 13,980 km at 82.5 kg, trading payload for fuel kg-for-kg at constant MTOW |

**The range optimum sits *faster* than textbook best-L/D would put it**, and the reason
is the engine, not the aerodynamics: BSFC depends on load fraction, so cruising harder
works the engine into a better part of its curve. That effect is worth several km/h of
optimum speed and it is a genuine coupling the simple Breguet range formula misses.

**A sanity check against a real aircraft.** The Vanilla VA001's 8-day record at 191 kg
is roughly 19,300 km of air distance if flown straight. v5.0 is a heavier aircraft with
a much larger payload and lands in the same order of magnitude. This is *not* the
discredited 16,000 km claim from the originating session revived — that was 200 kg on
BSFC 230 g/kWh with no stall margin; this is 320 kg on ~310 g/kWh part-load with the
stall margin active.

**A 10,000 km trip**, marched step by step at 200 km/h: **50.0 hours, 122.3 kg of fuel
burned, 50.1 kg remaining** — which is a meaningful reserve, and the only place in this
repository where a reserve appears at all.

### 8.3 The speed envelope

At the 4,000 m loiter altitude, from the drag polar and the rated shaft power:

| | MTOW 320 kg | mid-burn 234 kg | dry 148 kg |
|---|---|---|---|
| **Stall, clean, C_Lmax 1.60** | **104.2 km/h** | 89.0 km/h | 70.7 km/h |
| Loiter TAS (C_L 1.2098) | 119.8 km/h | 102.4 km/h | 81.4 km/h |
| **Maximum level speed, zero power margin** | **206.9 km/h** | 211.9 km/h | **215.1 km/h** |
| Maximum level speed at sea level | 183.2 km/h | 186.4 km/h | 188.5 km/h |
| Shaft power at 200 km/h, MTOW | 10.05 kW = **92.6% of rated** | | |

**200 km/h is the practical maximum**, at 93% of rated power. 206.9 km/h is the speed at
which the power margin reaches exactly zero, which is not a speed anyone flies.

**The stall speed is the operationally interesting number, and it is why the loiter
speed is not available at the start of the mission.** Stall at MTOW is 104.2 km/h and
the *mean* loiter speed across the burn is 101.8 km/h — **below the clean stall speed
at full fuel.** The aircraft cannot fly its own mean loiter condition until it has
burned off fuel; at MTOW it must fly 119.8 km/h, and it settles onto the slower
condition progressively. The endurance integration models this correctly (it computes
speed from instantaneous weight at every step), but the mission-planning consequence
should be stated: **the first hours of the mission are flown faster, higher-powered and
closer to the stall boundary than the headline loiter figure suggests.**

The margin against stall at MTOW, at the loiter condition, is exactly the 1.15 factor
the stall constraint imposes — 15% on speed, and it is *binding*, not chosen.

### 8.4 The range figure is not flyable with the recorded propulsion set

**This is the largest single caveat in this section, and it is not in
`scripts/range_analysis.py`.**

The range calculation holds propeller efficiency at **0.8529** — the *loiter* value —
at every cruise speed, and guards only against exceeding rated *engine power*. It never
asks whether the propeller can turn fast enough to deliver that power as thrust.

Running `argus7.prop.bemt` on the recorded 1.04 m, p/D 0.95, two-blade disc at each
cruise condition:

| Cruise speed | Thrust required at MTOW | Prop rpm to make it | η there | **Crank rpm through 3.659:1** |
|---|---|---|---|---|
| 102 km/h (loiter, MTOW) | 115.5 N | 2,240 | 0.828 | 8,196 |
| **134 km/h (best range)** | 103.4 N | **2,500** | **0.875** | **9,148 — 122% of rating** |
| 170 km/h | 118.4 N | 2,990 | 0.887 | 10,940 — 146% |
| 200 km/h | 144.0 N | >3,400 | — | >12,400 — 165% |

The propeller efficiency at those speeds is **better** than 0.8529, not worse — 0.875
to 0.889 — so the range figure is conservative in that one respect. **But the crank
speeds required are 22% to 65% above the 7,500 rpm rating the engine deck assumes**,
and `argus7/prop/engine.py`'s own overspeed ceiling is 1.15× (8,625 rpm).

Holding the crank to that 8,625 rpm ceiling, the fixed-pitch disc turns 2,357 rpm, and
the maximum level speed it can actually deliver is:

| | Maximum level speed, gearing-limited |
|---|---|
| MTOW 320 kg | **122.0 km/h** (shaft power used: 4.09 kW of 10.85) |
| mid-burn 234 kg | **130.5 km/h** (3.29 kW of 10.85) |

**The aircraft is not power-limited at 207 km/h. It is gearing-limited at about
122 km/h at MTOW, with two-thirds of its installed power unusable**, because a
fixed-pitch propeller on a fixed reduction ratio can only convert power to thrust
within a narrow band of advance ratio. **The 134 km/h best-range speed sits just
outside that band at MTOW and just inside it once fuel has burned off.**

**This is the same defect family as v1.0's C_P 0.911, seen from the other side.** v1.0's
propeller could not *absorb* its engine; v5.0's cannot *deliver* its engine at any
speed but the one it was optimised for. It does not affect the loiter mission at all —
the design mission — because loiter is where the propeller was solved. It invalidates
the ferry mission as currently specified.

**What settles it, and none of it is a redesign:** re-solve the reduction ratio jointly
with diameter and pitch against *both* missions; or accept two propellers (a loiter
blade and a ferry blade, a bolt-change on the ground); or reconsider variable pitch,
whose §4.5 dismissal was argued **on the loiter mission alone** and does not survive
this section. The 7,500 rpm rating is itself an assumption in `argus7/prop/engine.py`,
not a datasheet, so a real engine's speed range may reopen part of the gap on its own.

**Until one of those is done, this report claims the 17,659 km as a property of the
airframe and its fuel load, not as a flight the aircraft can perform.**

### 8.5 What else the range figure does not contain

- **Still air.** A 30 km/h headwind costs about 22% of range. There is no wind model
  anywhere in this repository.
- **No reserve, no climb, no descent, no diversion, no hold.** Fuel is burned to dry
  tanks. The 10,000 km case in §8.2 is the only calculation here with anything
  resembling a reserve, and that reserve is an outcome, not a requirement.
- **The full-load BSFC in `scripts/range_analysis.py` is hardcoded at 0.2506 kg/kWh**,
  the stage-1 optimiser's value, where the v5.0 design point uses 0.250. The effect is
  under 0.25% on range and in the conservative direction, but it is a number typed into
  a script rather than read from the design file, which is exactly what the provenance
  discipline exists to prevent.
- **Every BSFC caveat in §4.4 applies unchanged.** At a verified 330 g/kWh the range
  falls in roughly the same proportion as the endurance — about 24%, to some 13,400 km.
- **The aeroelastic clearance in §6.4 was checked against the 207 km/h power limit**,
  which §8.4 now shows is not the real limit. The margin only grows.

---

## 9. The lineage, and what each superseded point got wrong

### 9.1 Five design points, four corrections

| File | Endurance | Span | SM full / dry | Status |
|---|---|---|---|---|
| `argus7_v1.yaml` | 4.70 d published, **3.16 d** measured | 9.26 m | **−44.0% / −82.2%** | **Published, defective.** Statically unstable at every fuel state; wing cannot hold its fuel (101.5 kg into 66.1); propeller cannot absorb its engine (C_P 0.911) |
| `argus7_v2.yaml` | 4.88 d | 11.54 m | **−8.66% / −23.52%** | **RETIRED.** Still unstable; mass budget 13.02 kg short, traced to an engine-mass credit applied twice. (README's lineage table gives 5.02 d for this row; that figure is from `opt_runs/scaling3.log`, a later 250 kg scaling point with a 12.31 m span, not from `argus7_v2.yaml`.) |
| `argus7_v3.yaml` | 6.33 d | 11.27 m | **+5.79% / +5.71%** | **Superseded.** Balances, but **below the spec's own 8% floor** — the optimiser searched a 5–15% window, a pre-registered threshold moved without a ruling. Also carried **v2.0's propeller**, 26% short of level-flight thrust at its own loiter point |
| `argus7_v4.yaml` | 6.99 d | **12.0015 m** | +12.78% / +13.72% | **Superseded.** Stability gate met; **span 1.5 mm over the 12.0 m limit, failing gate G3** with zero buildable margin. Propeller re-solved at its own point |
| `argus7_v5.yaml` | **6.97 d** | **11.8558 m** | **+12.72% / +13.68%** | **Current.** 8 of 9 gates pass; the ninth (G7) is the engine and is unchanged since v1.0 |

**These are not variants of one aircraft; they are successive corrections**, and each
one was made because a check that had never been run was run.

**What v4.0 → v5.0 cost.** Almost nothing: 0.02 days of endurance to buy 144 mm of span
margin instead of −1.5 mm. The two design points are otherwise near-identical
(t/c 0.22, taper 0.25, x_le_frac ≈ 0.4076, tail volume 0.602, the same propeller and
gearing). **That the 12 m gate is nearly free at this MTOW is itself information**: the
optimiser's unconstrained-span answer at the same stability window sits at **14.47 m
and 7.16 d** (`opt_runs/layout_sm8.json`), so the transport limit costs about
**4.5 hours**, not days.

### 9.2 The propeller defect, and why it is a process finding

v3.0 was published in the previous revision of this report with a propeller that could
not hold it in level flight. The mechanism was not carelessness at the design point; it
was that **`scripts/prop_design_sweep.py` and `scripts/prop_refine.py` hardcode the
design file they load and the boom station they check against.** Two scripts that take
no arguments quietly returned answers for a retired aircraft, three design points in a
row, and each time the answer was copied into a design file and quoted in a report.

The fix applied at v4.0 and carried to v5.0 was to solve the propeller at the actual
design point. **The fix not applied is to parameterise the scripts**, which is why §4.5
still records that no committed script reproduces v5.0's propeller.

---

## 10. What changed from v1.0, claim by claim

| v1.0 claim | Status | v3.0 | **v5.0 / measured** | Where |
|---|---|---|---|---|
| Loiter endurance **4.70 d (112.8 h)** | **Reproduces arithmetically, wrong physically** | 6.33 d | **6.97 d as recorded, 6.94 d at the design file's own η_prop.** v1.0 is 112.977 h on its own polar (+0.16%); **3.16 d** once the engine is modelled at its 19% load | `opt_runs/final.json`; §4.2, §7.1 |
| **Static margin +14.7% MAC at CG 42%** | **DOES NOT REPRODUCE** | +5.79% (fails the 8% floor) | **+12.72% full / +13.68% dry — inside the 8–20% gate on all four readings.** v1.0 measures **−44.0% / −82.2%** | `argus7.analysis.balance`; §5.1, §5.4 |
| CG window 38–46% MAC | **Missed on v1.0, met on v5.0** | 39.6% | **41.7% full → 40.8% dry — inside the published window at every fuel state** | §5.3 |
| Fuel **101.5 kg in wing tanks at the AC** | **v1.0's WING CANNOT HOLD IT** | 160.6 into 168.0 (+4.4%) | **172.4 into 190.4 (+10.4%), and it survives mogas density (+5.5%)**. v1.0's capacity is **66.1 kg** on measured geometry | `wing_fuel_capacity_kg`; §12.2 |
| **CG travel <0.5% MAC** (design pack) | **Fails by 76× on v1.0** | −0.08% (achieved) | **+0.95% MAC — close, in the safe direction, and inside a passing stability window rather than below it** | §5.3 |
| **V_h = 0.68** (§2 tail row) | **DOES NOT CLOSE** | 0.4218, closes | **0.6018, closes.** v1.0's S_h 0.31 m² with a 3.2 m arm gives **V_h 0.5765** (17.9% off) | xfail in `tests/test_geometry_closure.py`; §2.1 |
| **0.813 m prop at 2,100 rpm on 17 kW** | **CANNOT ABSORB ITS ENGINE** | inherited from v2.0, **26% short of thrust** | **1.04 m at 2,050 rpm on 10.849 kW, absorbing 101% at climb and making 110% of loiter thrust — solved at this design point** | `tests/test_bemt.py`; §4.1, §4.5 |
| Reduction **2.3:1** | **Impossible** | 3.947:1 (v2.0's, wrong for v3.0) | **3.659:1 — and 2,050 × 3.659 = 7,501 rpm, on the assumed rating** | §4.5 |
| Prop η **0.84 assumed** | Slightly pessimistic | 0.858 claimed, 0.853 real | **0.8529 at the design point.** Note the mission was integrated at 0.858 | §4.5, §7.1 |
| BSFC **270 g/kWh flat** | **Wrong regime** | 339 g/kWh | **339.3 g/kWh** at 30.0% load. v1.0's installation gives **425** | §4.3 |
| **BSFC 250 → +0.5 d** | ❌ **WRONG** | — | **+0.377 d.** +0.5 d would need 244 g/kWh | §7.4 |
| **C_D0 0.016 → +0.36 d** | ✅ correct | — | **+0.358 d** | §7.4 |
| **3,000 m → +0.23 d** | ❌ **WRONG** | — | **+0.198 d** | §7.4 |
| C_D0 = 0.020 "realistic" | Ambiguous, and the ambiguity matters | 0.01588 | **0.01690.** The build-up returns 0.01368 with the measured laminar run; on v1.0 it returned 0.0200 with the wing assumed fully turbulent | xfail in `tests/test_buildup.py`; §3.2 |
| L/D_max 27.1 at C_D0 0.020 | Consistent | 29.15 at loiter | **30.42 max, 30.02 at loiter** | §3.1, §8.1 |
| e = 0.85 | Now derived, not asserted | 0.8482 | **0.8101 from 45 AVL runs plus an explicit viscous term — but read at taper 0.25, outside the sweep's 0.30–0.60 range** | §3.4 |
| MTOW 250 kg | **Superseded, and the band is crossed** | 312.93 (+25%) | **320.00 kg (+28%), at the optimiser's bound.** v1.0 §9's whole regulatory case is built at 250 kg | §12.4 |
| High AR is the route to endurance | **Contradicted** | — | AVL measures span efficiency nearly flat in AR (0.989 at AR 14 → 0.969 at AR 30). AR is not a strong lever; span and MTOW are | §3.4 |
| Wing 32.5 kg | Superseded | 45.39 kg | **40.63 kg** on a 47% larger wing — 7.10 kg/m² against 8.33, and **4.0% below the recommended build's areal density**, which is a warning not a win | §6.1 |
| *(no v1.0 claim)* Range | **New** | — | **17,659 km at 134 km/h**, and **not flyable with the recorded gearing** | §8 |
| *(no v1.0 claim)* Speed envelope | **New** | — | **Stall 104.2 km/h at MTOW; V_max 206.9 km/h on power, ~122 km/h on gearing** | §8.3, §8.4 |
| *(no v1.0 claim)* Structure | **New, and it is a correction** | — | **Tip deflection 14.4% of semi-span at limit (cross-validated); compression caps buckle at 80 MPa against 600 applied.** The mass model is optimistic | §6 |
| *(no v1.0 claim)* MTOW scaling law | **Not determined, and the earlier claim is withdrawn** | — | Three fits of the same quantity give exponents **0.869, 0.998 and 1.452**. Only engine power scales cleanly (MTOW^0.82, 6.1% scatter) because climb pins it | §12.5 |
| Premortem (Annex A) | **Still valid, unchanged** | — | The failure modes, tripwires and decision rule in v1.0 Annex A are about the *programme*, not the design point. The engine-numbers mode (#3) has grown in weight | v1.0 Annex A |

**A correction to the programme's own quotation of the fuel-volume defect.** The
repository has been quoting v1.0 as short by ~62 kg of tank. On honestly-measured
geometry it is short by **35.4 kg** (101.5 required, 66.1 available). Still a hard
fail, but the number the programme was quoting overstated it by 78%. The cause was
two conflated fractions in the capacity model — *fraction of chord* with *fraction of
section area*, and *fraction of span* with *fraction of volume*. A 15–65% chord box
holds **71.6%** of an FX 63-137's section area, not 50%; the inner 80% of a tapered
span holds **90.7–94.0%** of volume, not 80%. Both were wrong in the conservative
direction, which still invalidates an optimum: a binding constraint in the wrong place
distorts every variable that touches it.

---

## 11. Verification
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

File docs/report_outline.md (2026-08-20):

# Outline — Engineering Design Report: 200 kg MTOW Ultra-Long-Endurance UAV
Source of truth: ../research/design_pack.md (all numbers verified by computation)
Figures: ../figures/design-pack/fig1..fig9 (PNG)

1. Mission Requirements & Design Philosophy (~1,500 w) — from the engineering dialogue: ring-wing origin, convergence to planar high-AR; requirements table; design drivers
2. Configuration Selection (~2,000 w) — planar vs delta vs annular vs multirotor/VTOL; quantified trades; fig6
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

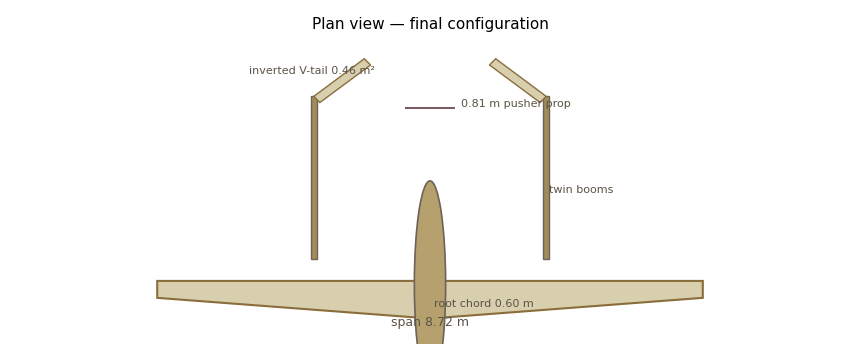
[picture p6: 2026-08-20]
figures/design-pack/fig9_planview.png

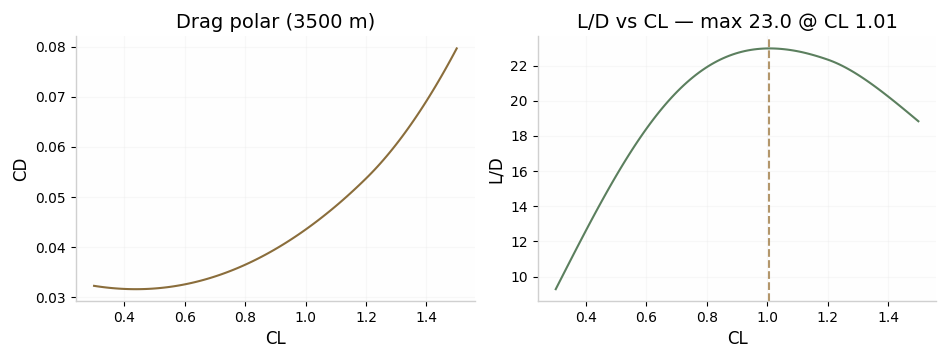
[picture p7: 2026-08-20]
figures/design-pack/fig2_polar.png

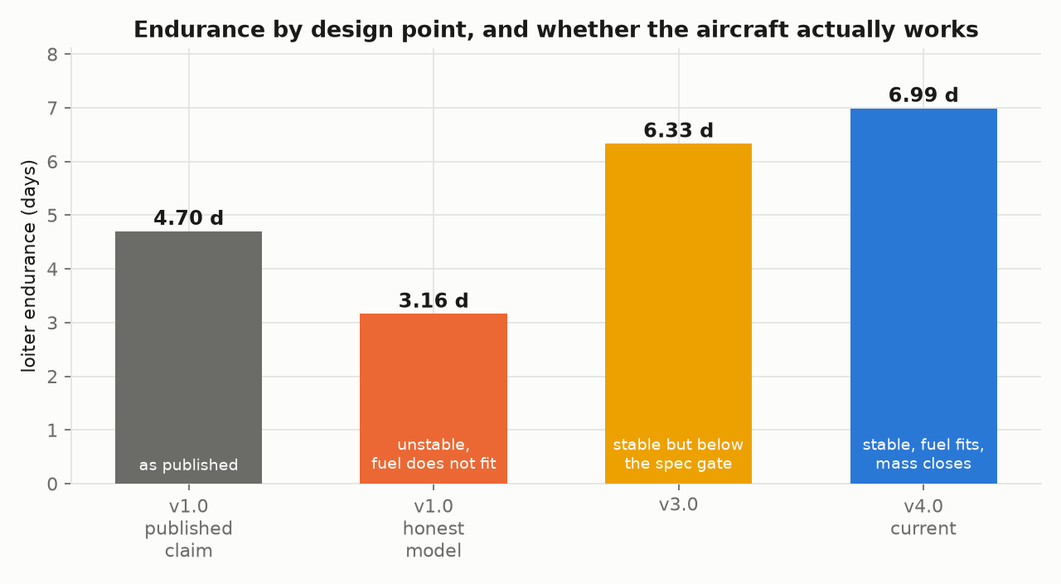
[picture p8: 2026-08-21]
figures/current/endurance_by_design.png

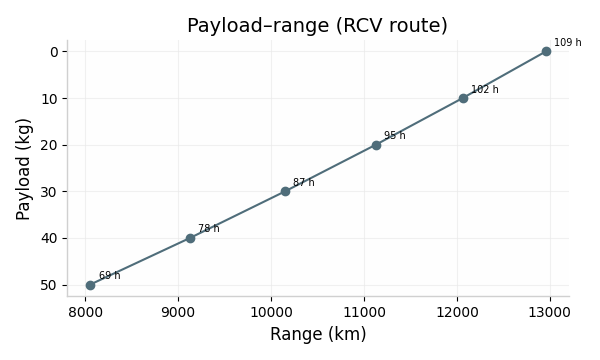
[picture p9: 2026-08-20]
figures/design-pack/fig8_payload_range.png

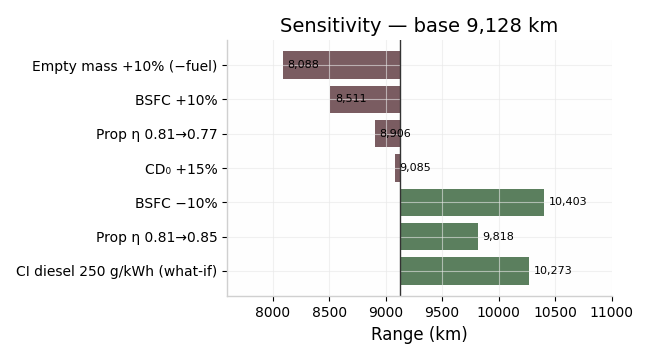
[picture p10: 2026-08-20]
figures/design-pack/fig7_sensitivity.png

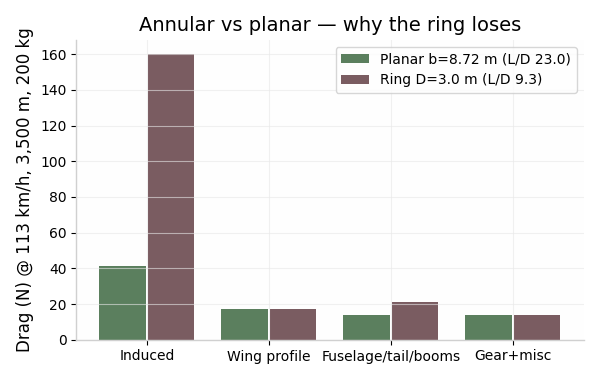
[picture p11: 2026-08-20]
figures/design-pack/fig6_annular.png

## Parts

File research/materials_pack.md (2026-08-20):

# ARGUS-7 — MATERIALS & MANUFACTURING DATA PACK

**Date:** 2026-08-20 · **Scope:** airframe materials and build methods for the 250 kg MTOW / 9.26 m span / AR 22 configuration of `docs/argus7_design_report.md` · **Companion to:** `research/design_pack.md`

**The question this pack was written to answer:** can a COTS-carbon-tube + 3D-printed build reach the 32.5 kg wing budget *and* the surface quality the FX 63-137 laminar bucket needs — and if not, what does it cost in endurance?

---

## 0. How to read this

Every numeric claim carries a bracketed source `[n]` and a provenance tag:

| Tag | Meaning |
|---|---|
| **[DS]** | Manufacturer datasheet, quoted verbatim (unit-converted only) |
| **[M]** | Measured / published experimental data (wind tunnel, mechanical test) |
| **[CALC]** | Computed here from the report's own geometry and load cases; the scripts are reproducible from the equations given inline |
| **[EST]** | Engineering estimate by the author of this pack — a judgement, not a measurement |
| **[DR]** | Derived from a secondary source that itself cites a primary one |
| **[UNV]** | Unverified — flagged as needing test or vendor confirmation |

Two honesty rules applied throughout:

1. **Where a datasheet is internally inconsistent, it is called out rather than quoted straight.** Two vendors' pultrusion datasheets in §3 fail a rule-of-mixtures cross-check; that is stated.
2. **Where this pack disagrees with the design report, it says so and shows the arithmetic.** Three such disagreements are in §2.2, §2.3 and §2.5.

**Calibration check on the endurance model.** All endurance deltas in this pack come from a re-implementation of the report's §4 loiter model (ISA 4000 m, ρ = 0.81935 kg/m³, S = 3.9 m², AR = 22, e = 0.85, C_L = C_Lmax/1.15² = 1.210, η_prop = 0.84, 500 W payload through a 0.75 alternator path, BSFC 270 g/kWh, integrating 250 kg → 148.5 kg). Fed C_D0 = 0.016 it returns **+8.6 h** against the C_D0 = 0.020 baseline; the report's own stated sensitivity is **+0.36 d = +8.64 h** [1]. The model is therefore a faithful reproduction of the report's model and is used only for *relative* deltas, scaled onto the report's headline 112.8 h. [CALC]

---

## 1. Answer first

**The sponsor's preference is right about spar caps and booms, wrong about skins, and roughly break-even about ribs.**

| Claim | Verdict | The number |
|---|---|---|
| Pultruded UD carbon rod/strip is a genuine spar-cap material | **Right, strongly** | Measured 1,682 MPa compressive / 133.8 GPa in the Rock West rod [2][DS]; 1,600 MPa / 140 GPa independently from a second pultruder [3][DS]. That is **2.8× the report's 600 MPa compression allowable** and **+15% specific stiffness over hand wet layup** [CALC] |
| COTS carbon tube can be the twin booms | **Right** | A 90 × 2.5 mm roll-wrapped tube runs at 102 MPa against a 620 MPa allowable; it is stiffness-, not strength-critical. 1.07 kg/m, 7.8 kg for two 3.65 m booms [CALC from 4][DS] |
| COTS carbon tube can be the **wing** spar | **Wrong** | A round tube inside a 12%-thick wing needs **2.07× the material** of a cap-and-web spar for the same moment — 9.0 kg vs 4.35 kg at σ = 600 MPa [CALC] |
| 3D-printed parts as primary structure | **Wrong** | At equal section, matching pultruded carbon's stiffness needs **15 kg of PA12-CF per 1 kg of carbon** [CALC from 2][5] |
| 3D-printed ribs, fairings, cradles, ducts | **Acceptable, at a 3.8–4.4× mass penalty vs foam/balsa ribs** | 4.10 kg of printed ribs at 100 mm pitch vs 0.91 kg in Rohacell/glass [CALC] |
| Heat-shrink film skin | **Wrong for this aircraft** | Not because of streamwise waviness (there is margin) but because film cannot form the leading edge, cannot hold the pressure-recovery contour, and its scalloping is a *spanwise* disturbance for which no favourable criterion exists — see §6.3 |
| Printed skin panels | **Wrong, decisively** | 2.63 kg/m² for a printed sandwich panel vs 0.68 kg/m² for CFRP/Rohacell at 1,700× *less* bending stiffness in the solid form [CALC]. +18.7 kg on the wing |

**The endurance answer, stated precisely.** The premise in the tasking — "if the build method forces C_D0 to 0.024+, roughly a day of endurance disappears" — is **half right, and right for a different reason than stated**:

- C_D0 = 0.024 **alone** costs **7.4 h (0.31 d)**, not a day. [CALC]
- The full consequence of a film-covered, non-laminar wing is **16.6–23.3 h (0.69–0.97 d)** — and *most of it is not the C_D0 term*. It decomposes as: aero drag −12.4 h, the measured −0.2 C_Lmax roughness penalty (which raises the stall-constrained loiter speed) −5.4 h, and +4.9 kg of extra structure displacing fuel −7.3 h. [CALC from 6][M]
- So: **yes, about a day — but the report's own "dirty 0.024" number understates the penalty by more than half**, because it counts only parasite drag and ignores both the C_Lmax loss and the mass.

**And a partial acquittal of the sponsor.** A hybrid that keeps pultruded caps and an accurate skin forward of 55% chord, but uses printed ribs and film aft, lands at **33.7 kg wing (+1.2 kg over budget)** and **−4.9 to −12.2 h**. That is a real option, not a strawman. See §11.

---

## 2. What the structure actually has to do

### 2.1 Load cases, re-derived from the report's own geometry

Span b = √(22 × 3.9) = **9.263 m**, semi-span s = 4.631 m; root/tip chord 0.581/0.261 m [1].

At n_ult = +5.7 g and MTOW 250 kg, with the report's *uniform* spanwise lift assumption:

- L_ult = 250 × 9.80665 × 5.7 = **13.97 kN**; per half-wing 6.99 kN; w = 1,508.7 N/m
- M_root = w·s²/2 = **16.18 kN·m** — the report says 16.2 kN·m ✓
- Elliptical alternative: 6.99 kN × (4/3π)·s = **13.73 kN·m** — the report says 13.7 ✓
- Structural depth 70 mm at root = 0.1205 × root chord → cap force = 16,180/0.070 = **231.1 kN** — the report says 232 kN ✓
- Cap areas: 231.1 kN / 800 MPa = **289 mm²** tension, / 600 MPa = **385 mm²** compression — the report says 290 / 387 ✓

[CALC] The report's structural chain is internally consistent and reproduces exactly. Three things follow from it that the report does not draw out.

### 2.2 Disagreement 1 — the report's spar-cap mass carries ~5.9 kg of unstated conservatism

The report quotes "cap mass 8.6–11.5 kg" [1]. Integrating the *sized* cap area A(y) = M(y)/(h(y)·σ) along the span for the real tapered planform, with M(y) = w(s−y)²/2 and h(y) = 0.1205·c(y):

| Cap sizing basis | Both wings, both caps |
|---|---|
| Tapered to the local moment, σ = 800/600 MPa, ρ = 1,550 kg/m³ | **3.81 kg** |
| Same, with a 10% minimum-gauge floor outboard | 3.96 kg |
| Same, at a conservative 600/450 MPa | 5.08 kg |
| **Constant root section carried over the full span** | **9.68 kg** |

[CALC] The report's 8.6–11.5 kg band brackets 9.68 kg, i.e. the report almost certainly costed a **constant-section cap running root to tip**. That is not how anyone builds a spar. **A properly tapered cap at the report's own allowables is 3.8–4.0 kg, leaving ~5.9 kg of unclaimed margin inside the 32.5 kg wing budget.** That margin is the single biggest reason the sponsor's heavier build methods come as close to closing as they do (§10).

### 2.3 Disagreement 2 — the wing is stiffness-critical, not strength-critical

Integrating curvature twice along the span with EI(y) from the strength-sized caps (E = 133.8 GPa pultruded [2][DS]):

| Condition | Tip deflection | % semi-span | Tip slope |
|---|---|---|---|
| 1 g cruise | 174 mm | 3.7% | 4.9° |
| Limit +3.8 g | **659 mm** | **14.2%** | 18.8° |
| Ultimate +5.7 g | 989 mm | 21.4% | 28.2° |

[CALC] Modern 15 m sailplanes deflect on the order of 8–10% of semi-span at limit load. 14.2% is at the flexible end of anything flown, and 21.4% at ultimate is far enough into geometric non-linearity that a linear beam calculation stops being trustworthy.

**Consequence for material selection:** if cap area is set by stiffness rather than strength, the figure of merit is **E/ρ, not σ/ρ**. That inverts the usual argument about pultruded rod. Pultruded rod's headline attraction is its 1,682 MPa compressive strength — but that strength is not what buys anything here. What buys something is that pultrusion delivers **133.8–140 GPa at Vf 60–65%** [2][3][DS] where a solo builder's hand wet layup at Vf ≈ 0.50 delivers ~117 GPa:

| Route | E (GPa) | ρ (g/cm³) | E/ρ | Source |
|---|---|---|---|---|
| Pultruded UD, T700-class | 133.8 | 1.523 | **87.9** | [2][DS] |
| Pultruded UD, second vendor | 140 | ~1.57 | 89.2 | [3][DS] |
| Vacuum-bagged UD prepreg, Vf 0.58 | ~134.8 | 1.548 | 87.1 | [CALC], rule of mixtures |
| Hand wet layup UD, Vf 0.50 | ~116.8 | 1.500 | 77.8 | [CALC], rule of mixtures |
| Roll-wrapped tube wall (bending layup) | 94.7 | 1.523 | 62.2 | [4][DS] |
| Filament-wound tube wall | 72.6 | 1.523 | 47.7 | [7][DS] |

**Pultruded strip matches prepreg on specific stiffness and beats hand wet layup by 13%, with no autoclave, no freezer, and no layup skill.** That is the real case for it, and it is a stronger case than the strength argument.

If the deflection is to be pulled back to a glider-like 9% of semi-span, EI must rise 1.57×. Two ways:
- **+57% standard-modulus cap area:** 3.8 → 5.97 kg (**+2.2 kg**)
- **High-modulus pultrusion (240 GPa, UMS45-class):** 1.71× EI at *unchanged mass*, but compressive strength drops to 1,000 MPa [3][DS] and price roughly 2.5× [8]

[CALC] The HM route is the better lever and it is only available *because* the section is pultruded — you cannot hand-lay HM fibre well.

### 2.4 Torsion is not demanding — which tells you what the skin is actually for

At V_D = 200 km/h EAS (q_D = 1,890 Pa) with C_m = 0.18 for the FX 63-137 class, the root torque is 293 N·m limit / 439 N·m ultimate. Carried in a D-nose torsion cell of enclosed area 85 cm², Bredt gives a shear flow of 25.8 kN/m — **0.26 mm** of ±45 skin at τ = 100 MPa. [CALC]

The shear web is equally undemanding: root shear 6.99 kN over a 70 mm depth needs **1.00 mm** at τ = 100 MPa, or 1.66 mm at a conservative 60 MPa. [CALC]

**So neither the web nor the skin is strength-driven.** Minimum gauge and buckling stability set the web; **aerodynamic shape-holding sets the skin.** This is why the skin question in §6 is a surface-quality question and not a structures question, and why "make the skin thinner to save mass" is the wrong lever — the mass is in whatever it takes to hold contour between supports.

### 2.5 Disagreement 3 — the wing cannot hold the fuel

> **Correction (added post-publication, P1 CAD rebuild):** the 0.68 "typical
> airfoil" shape factor used below is measurably wrong for this design's
> actual section. Loading the real FX 63-137 coordinates
> (`data/airfoils/fx63137.dat`) and computing the enclosed area directly by
> shoelace integration gives a shape factor of **0.6062**, not 0.68 — 0.68
> is **+12.2% biased high** for this aerofoil (`0.68/0.6062 = 1.122`; see
> `tests/test_cad_wing.py::test_wing_planform_area_matches_spec`, which
> found and fixed the same bias in the CAD volume check). Propagating the
> corrected factor through this section's own arithmetic:
> `160 L × 0.6062/0.68 = 142.6 L gross` (≈ **143 L**, not 160 L). The
> "56–72 L usable" figure below scales down by the same ratio to
> **~50–64 L usable**, still well short of the report's 120 L requirement —
> the qualitative finding (the wing cannot hold the fuel) is unchanged and,
> if anything, worse than originally stated. The rest of this section is
> left as originally written rather than silently edited; treat 0.68 and
> everything downstream of it (160 L, 56–72 L) as superseded by the 143 L /
> ~50–64 L figures above. See `README.md`'s "Known gaps" for the
> project-level tracking of this finding.

Wing internal volume, taking the enclosed airfoil area as 0.68·c·t = 0.0932·c² for a 13.7% section:

V = 2 × 0.0932 × ∫₀ˢ c(y)² dy = 2 × 0.0932 × 0.8604 = **0.160 m³ = 160 L gross**

Usable integral tankage is realistically 35–45% of gross wing volume once the spar box, ribs, control runs, dry bays and expansion space are removed → **56–72 L**. The report requires **~120 L** in "wing tanks at the AC" [1]. [CALC]

This is outside this pack's remit but it lands squarely on it: closing the fuel volume forces either (a) sealed integral wet-wing bays, which is a hard requirement for a bonded rod-and-tube build and rules out unsealed printed ribs inside the tank bays, or (b) fuselage-pod tankage, which reopens the CG-travel question the report closed by putting fuel at the AC. Flagged in §13.

---

## 3. Pultruded UD carbon rod, strip and plate

### 3.1 Measured properties — three sources, cross-checked

| Property | Rock West 47312 rod, Ø 0.432″ [2] | Compositesplaza pultrusion [3] | R&G / DPP (Van Dijk) [8] |
|---|---|---|---|
| Fibre | Toray T700S, ">60%" | Torayca T700 or equiv. | HT carbon, T300/T700 or equiv. |
| Fibre volume fraction | not stated | **±63%** | 60–65% (DPP), ~63% (R&G) |
| Axial modulus E_x | **133.8 GPa** (1.94×10⁷ psi) | **140 GPa** | ">200 GPa" — see note |
| Axial tensile strength | **2,372 MPa** (344 ksi) | **2,500 MPa** | ">3 GPa" — see note |
| **Axial compressive strength** | **1,682 MPa** (244 ksi) | **1,600 MPa** | not stated |
| Transverse modulus E_y | 8.69 GPa | — | — |
| Transverse tensile | 63.4 MPa | — | — |
| Shear modulus G_xy | 5.52 GPa | — | — |
| ILSS | — | — | ~100 MPa |
| Density | **1.523 g/cm³** (0.055 lb/in³) | ~1.55–1.60 (back-calc from g/m) | "approx. 1.78" — see note |
| Resin / Tg | bisphenol-A epoxy, **Tg 120 °C** | bisphenol-A epoxy, **Tg 120 °C** | HDT ~120 °C |
| Straightness | — | 2 mm / 1,000 mm | ≤1 mm / m |

[DS] for all. Unit conversions at 1 psi = 6.894757 kPa.

**Two datasheet problems, called out:**

- **R&G's ">200 GPa modulus / >3 GPa tensile" are virgin-fibre values, not laminate values.** At Vf 0.63 with T700 (230 GPa fibre), rule of mixtures gives 0.63 × 230 + 0.37 × 3.5 = **146 GPa** — you cannot get 200 GPa out of HT fibre at 63% Vf. Use 134–146 GPa. [CALC]
- **R&G's stated density of 1.78 g/cm³ is ~13% too high.** Rule of mixtures at Vf 0.63 (fibre 1.80, epoxy 1.20) gives **1.578 g/cm³**; Rock West's independently stated 1.523 and Compositesplaza's back-calculated 1.55–1.60 g/m both agree with the mixture rule. **Design to 1.52–1.60 g/cm³, not 1.78** — using 1.78 would over-predict cap mass by 13%. [CALC]

**The compressive number is the one that matters and it cross-validates.** Two independent pultruders quote 1,600 and 1,682 MPa. This is the strongest single result in this pack: pultrusion's straight, void-free, high-Vf fibre is precisely what compressive strength is sensitive to [9][DR].

### 3.2 How this compares with the report's allowables

| | Report allowable [1] | Measured material [2][3] | Ratio |
|---|---|---|---|
| Tension | 800 MPa | 2,372–2,500 MPa | **3.0–3.1×** |
| Compression | 600 MPa | 1,600–1,682 MPa | **2.7–2.8×** |
| Ultimate strain at the allowable | 0.60% / 0.45% (at E = 133.8 GPa) | 1.77% / 1.26% break strain | — |

[CALC] The report's allowables sit at a knockdown of ~0.34–0.36 on measured material strength. That is *not* excessive for a spar cap: the knockdown has to cover local buckling of the cap between web stabilisation points, fibre waviness, bondline defects, impact damage tolerance, hot/wet, and statistical B-basis. Published sailplane-structures practice puts a "high tensile fibre / tough resin system" cap at ~900 MPa design compression at ultimate with fracture above 1,000 MPa, justified by the spar being protected from impact and free of stress raisers [10][DR].

**Conclusion:** the report's 600 MPa compression allowable is *conservative by roughly 1.5×* against sailplane practice and by 2.8× against the raw material — and, per §2.3, is not the binding constraint anyway. Keeping it is the right call for a first article, but it should be recorded as a deliberate 1.5× reserve, not as the material limit.

### 3.3 Round rod vs rectangular strip vs plate — take the strip

Round rod packed into a cap groove loses to geometry:

- Hexagonal close packing of circles is 90.7% theoretical; a hand-packed bundle in a resin-filled groove realistically achieves **75–85%** [EST]. The remaining volume is neat resin: mass with no stiffness.
- To deliver 385 mm² of carbon you must cut a groove of **450–515 mm²** — into a spar that is only 70 mm deep at the root.
- Rectangular strip stacks at **>95%** with thin, uniform, easily-controlled bondlines, and the flat interfaces let you inspect for voids.

[CALC] **Specify pultruded rectangular strip (or plate), not round rod, for spar caps.** Round rod is the right product for pushrods, control links, rib capstrips, trailing-edge stiffeners and localised reinforcement.

### 3.4 Available sections and the splice problem — this is the real constraint

| Supplier | Sections held | Stock length | Note |
|---|---|---|---|
| Compositesplaza (NL) [3] | Ø 0.5–10 mm rod; 3×0.8, 6×0.8, 8×0.8, **20×1.0 mm** strip; small tubes | **1,000 mm only** | straightness 2 mm/m |
| R&G / DPP (DE/NL) [8] | round, square, half-round, rectangular incl. **50 × 10 mm** and 15 × 3 mm | **1,000–2,000 mm** | DPP = Van Dijk Pultrusion Products, premium grade |
| Rock West (US) [2] | Ø 0.011–0.5″ rod; strips 0.019×0.118″, **0.125 × 0.325″** | up to **96″ (2.44 m)** | 0.125×0.325″ = 26.2 mm² |

**The semi-span is 4.631 m. No supplier holds stock that long.** [DS]

This is the single most important practical finding about pultruded caps and it is not a showstopper — pultrusion is a continuous process and long lengths are a mill-order item (wind-blade spar-cap pultrusions are supplied in coiled tens of metres [9][DR]) — but a solo builder ordering from stock must splice. The correct method is a **glulam-style staggered butt**: build the cap as a stack of 4–8 strips, butt-joint each strip, and stagger adjacent joints by ≥20× the strip thickness, so at any station only 1/n of the cap area is discontinuous and the load ferries around the joint through the adjacent laminae in shear.

Sizing check: with 8 strips of 3 mm × 16 mm (48 mm² each, 384 mm² total ≈ the required root area), one butt joint locally removes 48 mm² = 12.5% of the cap. Transferring 231.1 × 0.125 = **28.9 kN** through the two adjacent bondlines at 30 MPa adhesive shear [11][DS] with a 50% peak-vs-average knockdown needs **2 × 16 mm × 60 mm** of overlap, i.e. a 60 mm stagger minimum; a 20t = 60 mm stagger satisfies it exactly, and 100 mm gives comfortable margin. [CALC]

**Rule: no butt joint inboard of 30% semi-span.** Inboard of that station the moment is high enough that a splice defect is a wing-loss event; buy or order continuous strip for the inner 1.4 m, splice only outboard.

### 3.5 Price

| Product | Price | €/kg or $/kg | Source |
|---|---|---|---|
| Rock West Ø 0.432″ rod × 72″ | $126.99 (clearance $63.49) | **$482/kg** ($241 clearance) | [2][DS] |
| R&G 20 × 2.0 mm × 1,000 mm strip (remainder stock) | from €14.27/pc | **€230/kg** | [8][DS] |
| Raw T700 12k UD fabric + laminating epoxy, hand layup | — | ~€90–150 for 4.2 kg of laminate | [EST] |

[CALC] **4.2 kg of pultruded spar caps costs €1,000–2,000 (add ~25% for waste and splice overlap → €1,250–2,600).** The same caps hand-laid cost €90–150 in materials.

**That €1,100–2,500 premium buys:** (a) 40–80 h of the highest-consequence layup on the aircraft, eliminated; (b) fibre volume fraction and straightness that a solo builder in a garage will not reproduce; (c) removal of the single failure mode most likely to be invisible until the wing breaks — fibre waviness in a compression cap. **On a €60k / one-pair-of-hands programme, this is the best-value line item in the whole build.**

### 3.6 Verdict on pultruded UD

**Adopt for spar caps, in rectangular strip form.** It is where the sponsor's preference is most clearly correct, and the reason is not the one usually given: the win is specific stiffness, quality assurance and eliminated labour, not headline strength.

---

## 4. Carbon tube — booms, and the tube-spar question

### 4.1 Roll-wrapped vs filament-wound: the trade is bending stiffness against torsional stiffness

Two real, in-stock products with published laminate allowables:

| | Roll-wrapped, 3k 2×2 twill outer + multidirectional uni core [4] | Filament-wound, standard modulus [7] | Clearwater reference laminates [12] |
|---|---|---|---|
| Part | RWC 45285, 3.000 × 3.125″ × 72″, wall 0.063″ (1.60 mm) | RWC 35165-U, 2.875 × 3.155″, wall 0.140″ (3.56 mm), to 15 ft | — |
| Fibre / resin | Tenax UTS50 / Eporite EHM32 | Grafil 34-700 | — |
| **E_x (axial)** | **94.7 GPa** | **72.6 GPa** | UD-"bending" 103 GPa; ±45-"torsion" 15.2 GPa |
| E_y (hoop) | 32.9 GPa | 33.2 GPa | — |
| **G_xy** | **11.68 GPa** | **22.53 GPa** | UD-"bending" 4.1 GPa; ±45-"torsion" 31 GPa |
| σ axial tension | 620 MPa | 455 MPa | UD 2,068 MPa |
| σ axial compression | 732 MPa | 510 MPa | — |
| Density | 1.523 g/cm³ | 1.523 g/cm³ | 1.55 |
| Mass | 0.591 kg/m | 1.302 kg/m | — |
| Tg | 107–121 °C (225–249 °F) | — | — |

[DS] all. Note that both vendors quote a *compressive* axial strength above the tensile one; that is characteristic of laminate-solver output rather than coupon test and should be treated as [UNV] — design to the tensile number.

**The trade is exactly as the fibre architecture predicts:** roll-wrapped gives +30% axial modulus (bending), filament-wound gives +93% shear modulus (torsion). **A twin boom carrying an inverted-V tail needs both.** Buying a generic "3K twill carbon tube" — which is largely ±45 fabric — gets you the torsional half and leaves you bending-soft. This is a specification, not a shopping decision.

### 4.2 Boom sizing for the inverted-V tail

Tail S_h = 0.31 m², arm 3.2 m, boom cantilever ≈ 3.4 m [1]. At V_D = 200 km/h EAS (q_D = 1,890 Pa) and C_N = 1.0 on the tail:

- limit tail load 586 N, ultimate 879 N, **440 N per boom**
- per-boom ultimate root bending **1,494 N·m**
- torque about the boom axis from a V-panel force acting at ~0.33 m along the panel: **≈150 N·m ultimate** [CALC]

| Tube | σ (MPa) | EI (kN·m²) | Tip defl. @ ult. | GJ (kN·m²) | Twist @ 150 N·m | kg/m | 2 booms, 3.65 m |
|---|---|---|---|---|---|---|---|
| 90 × 1.6 mm roll-wrapped [4] | 155 | 41.1 | **140 mm** | 10.2 | **2.9°** | 0.689 | 5.03 kg |
| 90 × 2.5 mm roll-wrapped | 102 | 62.3 | 93 mm | 15.4 | 1.9° | 1.065 | **7.78 kg** |
| 90 × 3.5 mm roll-wrapped | 76 | 84.2 | 68 mm | 20.8 | 1.4° | 1.474 | 10.76 kg |
| 80 × 3.56 mm filament-wound [7] | 95 | 45.8 | 126 mm | 28.4 | 1.0° | 1.339 | 9.78 kg |
| 90 × 2.5 mm, 60/40 UD/±45 custom | 102 | 52.6 | 109 mm | 23.7 | 1.3° | 1.065 | 7.78 kg |

[CALC from 4][7][DS]

**Findings:**

1. **The booms are stiffness-critical by a wide margin.** Even the thinnest tube runs at 155 MPa against a 620 MPa allowable — a margin of 4.0×. Nothing about boom *strength* is difficult.
2. **A 140 mm tip deflection is 2.4° of tail incidence change**, which directly erodes tail effectiveness and feeds the aeroelastic case. 90 × 2.5 mm is the practical minimum.
3. **A larger, thinner boom is a better trade than a thicker one.** Going 90 → 110 mm at the same wall raises I by 1.84× for 1.24× the mass — a net 48% gain in stiffness per kilogram. The drag cost is ΔC_D0 = +0.00042 → **−0.83 h of endurance** [CALC]. Trading 0.83 h for 2 kg of boom mass (which itself is worth 3.0 h of endurance, §11) is clearly favourable.
4. The report's current `booms.diameter_m: 0.09` is tagged `assumption` in `design/argus7_v1.yaml`. **It should be re-opened as a design variable at 100–110 mm.**

### 4.3 Can a COTS tube be the *wing* spar? No — and the penalty is a clean 2.07×

For a cap-and-web spar of depth h: required cap area = 2M/(σ·h).
For a round tube of diameter D carrying the same moment: section modulus πR²t = M/σ, and wall area = 2πRt = **4M/(σ·D)**.

Ratio = 2h/D. A tube must fit inside the wing (D ≈ 0.85 × local thickness) while a cap-and-web spar can put material at ≈0.88 × thickness, so:

**ratio = 2 × 0.88 / 0.85 = 2.07×** [CALC]

Integrated over the span at σ = 600 MPa:

| Spar architecture | Mass, both wings |
|---|---|
| Cap-and-web (caps only) | **4.35 kg** |
| Round tube spar | **9.01 kg** |

And it gets worse in practice, because the tube diameter must shrink outboard:

| y/s | chord | wing thickness | max tube OD |
|---|---|---|---|
| 0.00 | 581 mm | 79.6 mm | 67.7 mm |
| 0.25 | 501 mm | 68.6 mm | 58.3 mm |
| 0.50 | 421 mm | 57.7 mm | 49.0 mm |
| 0.75 | 341 mm | 46.7 mm | 39.7 mm |

[CALC] **A single constant-diameter tube cannot run out the span.** The build requires 3–4 telescoped/stepped sections with bonded overlap joints — which adds a further **+20–30%** over the ideal-taper 9.01 kg (call it 10.8–11.7 kg) [EST], plus 6–8 more joints in the primary load path.

**Offsetting credit:** the tube carries shear and torsion itself, so it deletes the shear web (0.8 kg) and reduces the demand on a D-nose torsion cell. Net honest comparison: **tube spar ≈ 9.0–11.7 kg vs cap+web ≈ 5.2 kg. The tube costs 3.8–6.5 kg of wing.** At the report's mass-to-endurance exchange rate (§11) that alone is **5.7–9.7 h of endurance**.

The geometry is unarguable: a circle puts most of its material near its own neutral axis, and a 12%-thick wing does not have the depth to spare.

### 4.4 Supply, sizes and price for the booms

- **Filament-wound is available to 15 ft (4.57 m) continuous** [7][DS] — long enough for a one-piece 3.65 m boom. Roll-wrapped stock at Rock West tops out around 72–96″ (1.83–2.44 m); a 3.65 m roll-wrapped boom is a custom mandrel order.
- 90 mm OD tubes are stocked in Europe (e.g. carbonwebshop's 90 mm range) and widely available from Asian drone-boom suppliers; observed listings for 90 × 86 mm × 1,000 mm run **$80–302** [13][UNV — marketplace listings, not vendor datasheets].
- Rock West's large filament-wound tubes are priced per 12″ increment; the 2.875″ family runs into four figures at 15 ft [7][DS]. **Budget €2,000–5,000 for two aerospace-sourced booms; €400–1,200 from a drone-boom supplier with unverified allowables.**

**Recommendation:** buy the booms from a supplier that will state E_x, G_xy and the layup. If the vendor cannot, treat the tube as [UNV] and coupon-test one before committing the tail.

### 4.5 Verdict on tube

**Adopt COTS tube for the booms (specify a mixed UD/±45 layup, 100–110 mm OD, ~2.5 mm wall). Reject it for the wing spar.**

---

## 5. 3D printing for aerostructures

### 5.1 Measured properties

| Material / process | ρ (g/cm³) | σ_t (MPa) | E (MPa) | Elong. (%) | Thermal | Source |
|---|---|---|---|---|---|---|
| **PA12, HP MJF** | 1.01 | 48 (yield 40) | **1,700** | 20 | — | [5][DS] |
| **PA12-CF, EOS CarbonMide (SLS)** | 1.04 | **72 / 56 / 25** (X/Y/Z) | **6,100 / 3,400 / 2,200** | 4.1 / 6.3 / 1.3 | T_melt 176 °C | [14][DS] |
| **PA6-CF, FDM (Bambu)** | 1.09 | **102 ± 7 (XY) / 48 ± 6 (Z)** | **4,430 ± 310 (XY) / 2,170 ± 230 (Z)** | 5.8 / 3.7 | **Tg 68 °C**, HDT 164 °C @1.8 MPa, 186 °C @0.45 MPa | [15][DS] |
| **PPS-CF10, FDM (Polymaker Fiberon)** | ~1.35 | 32 (as listed) — other vendors 74 | 5,314 dry; flex 4,647 (XY) | — | **HDT 252.5 °C @0.45 MPa** | [16][DS], [17][DR] |
| PA12-CF, FDM | ~1.06 | 60–75 | 3,500–5,500 | 3–6 | — | [17][DR][UNV] |
| PETG-CF, FDM | ~1.30 | 45–55 | 3,500–5,000 | 2–4 | Tg ~80 °C | [17][DR][UNV] |
| — for reference — | | | | | | |
| Pultruded UD carbon | 1.52 | 2,372 | 133,800 | 1.8 | Tg 120 °C | [2][DS] |
| 6061-T6 aluminium | 2.70 | 241 | 68,900 | 12 | — | [12][DS] |

Charpy (CarbonMide, unnotched, 23 °C): 20.5 / 27.5 / **5.5** kJ/m² X/Y/Z; notched 5.3 / 4.4 / **2.1** [14][DS]. MJF PA12 unfilled: 45 kJ/m² [5][DS] — **the unfilled grade is 2× tougher than the carbon-filled one and 8× tougher in Z.**

### 5.2 Anisotropy is the design constraint, not strength

CarbonMide Z-direction is **35% of X strength and 36% of X modulus**, with break strain down from 4.1% to **1.3%** [14][DS]. Bambu PA6-CF Z is **47% of XY strength, 49% of XY modulus** [15][DS].

[CALC] **Every printed part on this aircraft must have its build orientation specified on the drawing, and the drawing must state which direction carries load.** A rib printed flat (load in-plane) is a different part from the same geometry printed upright. This is a documentation obligation, not a material property — and it is the most common way printed aero parts fail.

### 5.3 Temperature — the real ceiling, and it is not HDT

The report's environment is "−5 to −15 °C at altitude" [1]. That is the benign case. The binding case is a **parked aircraft in sun**.

Measured reference: at 38 °C ambient, a *white* fibreglass-coated foam box reached **66 °C** surface; a *black* one exceeded **104 °C** [18][M]. Sailplanes are painted white specifically to keep the laminate below the epoxy Tg of ~88 °C [18][DR].

Against that:

| Material | Relevant temperature | Verdict for a sun-exposed part |
|---|---|---|
| PA6-CF | **Tg 68 °C dry** [15][DS] — and PA6's Tg falls steeply with absorbed water | **Fails.** A dark printed part in sun sits above Tg; creep rate multiplies |
| PA12 (MJF/SLS) | Tg ~40–50 °C; melt 176 °C; HDT 97 °C @1.8 MPa [5][14][DS] | Marginal. Survives, but see §5.4 |
| PPS-CF | HDT 252 °C @0.45 MPa, continuous use ~220 °C [16][17][DS/DR] | Passes comfortably, incl. engine bay |
| PETG-CF | Tg ~80 °C [17][DR] | Marginal for sun; fails in engine bay |
| Room-temperature-cure laminating epoxy | Tg 50–70 °C as cured; 80–90 °C after a 12–24 h elevated post-cure [19][DR] | **Fails without post-cure.** Post-cure is mandatory |
| Hysol EA 9394 paste adhesive | **Tg 78 °C dry / 68 °C wet** [11][DS] | Marginal — and its lap shear at 82 °C is 20.7 MPa vs 28.9 at 25 °C, a **28% loss** |

**Three hard rules follow:**
1. **Paint the aircraft white or very light.** This is a structural requirement, not cosmetic.
2. **Post-cure every room-temperature-cured epoxy joint** at 50–60 °C for ≥12 h before flight.
3. **No PA6-CF anywhere in sun or in the engine bay.** PA12 for exterior printed parts, PPS-CF for anything hot.
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

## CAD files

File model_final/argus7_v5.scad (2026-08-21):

// ==== GENERATED FILE - DO NOT EDIT ====
// Generated by argus7.cad.to_openscad from design 'ARGUS-7' variant v5.0.
// Edit design/*.yaml and regenerate. Hand-editing reintroduces the
// geometry-drift defect this pipeline exists to prevent.
// S = 5.7201 m2 | AR = 24.5728 | b = 11.8558 m
// c_root = 0.7720 m | c_tip = 0.1930 m | MAC = 0.5404 m
// tail: c_root = 0.4024 m | c_tip = 0.2213 m | MAC = 0.3206 m
// booms: x_fwd = 1.2355 m | x_aft = 7.4852 m | y_station = 0.7943 m
// Axes: x aft, y starboard, z up.
$fn = 64;
airfoil = [[1.00000,0.00000], [0.99893,0.00082], [0.99572,0.00249], [0.99039,0.00501], [0.98296,0.00818], [0.97347,0.01189], [0.96194,0.01601], [0.94844,0.02043], [0.93301,0.02516], [0.91573,0.03018], [0.89668,0.03553], [0.87592,0.04114], [0.85355,0.04711], [0.82967,0.05323], [0.80438,0.05962], [0.77779,0.06605], [0.75000,0.07273], [0.72114,0.07927], [0.69134,0.08590], [0.66072,0.09204], [0.62941,0.09804], [0.59755,0.10331], [0.56526,0.10823], [0.53270,0.11221], [0.50000,0.11578], [0.46730,0.11833], [0.43474,0.12042], [0.40245,0.12137], [0.37059,0.12191], [0.33928,0.12128], [0.30866,0.12024], [0.27886,0.11792], [0.25000,0.11522], [0.22221,0.11122], [0.19562,0.10704], [0.17033,0.10165], [0.14645,0.09622], [0.12408,0.08961], [0.10332,0.08313], [0.08427,0.07555], [0.06699,0.06836], [0.05156,0.06005], [0.03806,0.05248], [0.02653,0.04480], [0.01704,0.03625], [0.00961,0.02740], [0.00428,0.01750], [0.00107,0.00900], [0.00000,0.00000], [0.00107,-0.00232], [0.00428,-0.00566], [0.00961,-0.00995], [0.01704,-0.01254], [0.02653,-0.01537], [0.03806,-0.01698], [0.05156,-0.01887], [0.06699,-0.01992], [0.08427,-0.02122], [0.10332,-0.02180], [0.12408,-0.02256], [0.14645,-0.02263], [0.17033,-0.02277], [0.19562,-0.02220], [0.22221,-0.02161], [0.25000,-0.02034], [0.27886,-0.01895], [0.30866,-0.01688], [0.33928,-0.01460], [0.37059,-0.01167], [0.40245,-0.00848], [0.43474,-0.00486], [0.46730,-0.00103], [0.50000,0.00307], [0.53270,0.00716], [0.56526,0.01112], [0.59755,0.01475], [0.62941,0.01813], [0.66072,0.02098], [0.69134,0.02345], [0.72114,0.02530], [0.75000,0.02668], [0.77779,0.02745], [0.80438,0.02768], [0.82967,0.02729], [0.85355,0.02631], [0.87592,0.02479], [0.89668,0.02284], [0.91573,0.02052], [0.93301,0.01794], [0.94844,0.01514], [0.96194,0.01219], [0.97347,0.00921], [0.98296,0.00630], [0.99039,0.00373], [0.99572,0.00169], [0.99893,0.00040], [1.00000,0.00000]];
airfoil_tail = [[1.00000,-0.00000], [0.99983,0.00002], [0.99931,0.00008], [0.99846,0.00019], [0.99726,0.00033], [0.99572,0.00052], [0.99384,0.00074], [0.99163,0.00101], [0.98907,0.00131], [0.98618,0.00166], [0.98296,0.00204], [0.97941,0.00246], [0.97553,0.00292], [0.97132,0.00341], [0.96679,0.00394], [0.96194,0.00450], [0.95677,0.00509], [0.95129,0.00572], [0.94550,0.00638], [0.93941,0.00706], [0.93301,0.00778], [0.92632,0.00852], [0.91934,0.00929], [0.91206,0.01008], [0.90451,0.01089], [0.89668,0.01173], [0.88857,0.01259], [0.88020,0.01346], [0.87157,0.01436], [0.86269,0.01527], [0.85355,0.01620], [0.84418,0.01714], [0.83457,0.01809], [0.82472,0.01906], [0.81466,0.02003], [0.80438,0.02101], [0.79389,0.02200], [0.78320,0.02300], [0.77232,0.02400], [0.76125,0.02500], [0.75000,0.02600], [0.73858,0.02701], [0.72700,0.02801], [0.71526,0.02901], [0.70337,0.03000], [0.69134,0.03099], [0.67918,0.03197], [0.66690,0.03294], [0.65451,0.03391], [0.64201,0.03485], [0.62941,0.03579], [0.61672,0.03671], [0.60396,0.03762], [0.59112,0.03850], [0.57822,0.03937], [0.56526,0.04021], [0.55226,0.04103], [0.53923,0.04183], [0.52617,0.04260], [0.51309,0.04334], [0.50000,0.04405], [0.48691,0.04473], [0.47383,0.04538], [0.46077,0.04599], [0.44774,0.04656], [0.43474,0.04710], [0.42178,0.04759], [0.40888,0.04804], [0.39604,0.04845], [0.38328,0.04882], [0.37059,0.04914], [0.35799,0.04941], [0.34549,0.04963], [0.33310,0.04980], [0.32082,0.04992], [0.30866,0.04999], [0.29663,0.05000], [0.28474,0.04996], [0.27300,0.04987], [0.26142,0.04972], [0.25000,0.04951], [0.23875,0.04924], [0.22768,0.04892], [0.21680,0.04853], [0.20611,0.04809], [0.19562,0.04759], [0.18534,0.04704], [0.17528,0.04642], [0.16543,0.04575], [0.15582,0.04502], [0.14645,0.04424], [0.13731,0.04339], [0.12843,0.04250], [0.11980,0.04154], [0.11143,0.04054], [0.10332,0.03948], [0.09549,0.03837], [0.08794,0.03722], [0.08066,0.03601], [0.07368,0.03475], [0.06699,0.03345], [0.06059,0.03211], [0.05450,0.03072], [0.04871,0.02929], [0.04323,0.02782], [0.03806,0.02632], [0.03321,0.02477], [0.02868,0.02319], [0.02447,0.02158], [0.02059,0.01993], [0.01704,0.01825], [0.01382,0.01654], [0.01093,0.01481], [0.00837,0.01304], [0.00616,0.01125], [0.00428,0.00944], [0.00274,0.00760], [0.00154,0.00573], [0.00069,0.00384], [0.00017,0.00193], [0.00000,0.00000], [0.00017,-0.00193], [0.00069,-0.00384], [0.00154,-0.00573], [0.00274,-0.00760], [0.00428,-0.00944], [0.00616,-0.01125], [0.00837,-0.01304], [0.01093,-0.01481], [0.01382,-0.01654], [0.01704,-0.01825], [0.02059,-0.01993], [0.02447,-0.02158], [0.02868,-0.02319], [0.03321,-0.02477], [0.03806,-0.02632], [0.04323,-0.02782], [0.04871,-0.02929], [0.05450,-0.03072], [0.06059,-0.03211], [0.06699,-0.03345], [0.07368,-0.03475], [0.08066,-0.03601], [0.08794,-0.03722], [0.09549,-0.03837], [0.10332,-0.03948], [0.11143,-0.04054], [0.11980,-0.04154], [0.12843,-0.04250], [0.13731,-0.04339], [0.14645,-0.04424], [0.15582,-0.04502], [0.16543,-0.04575], [0.17528,-0.04642], [0.18534,-0.04704], [0.19562,-0.04759], [0.20611,-0.04809], [0.21680,-0.04853], [0.22768,-0.04892], [0.23875,-0.04924], [0.25000,-0.04951], [0.26142,-0.04972], [0.27300,-0.04987], [0.28474,-0.04996], [0.29663,-0.05000], [0.30866,-0.04999], [0.32082,-0.04992], [0.33310,-0.04980], [0.34549,-0.04963], [0.35799,-0.04941], [0.37059,-0.04914], [0.38328,-0.04882], [0.39604,-0.04845], [0.40888,-0.04804], [0.42178,-0.04759], [0.43474,-0.04710], [0.44774,-0.04656], [0.46077,-0.04599], [0.47383,-0.04538], [0.48691,-0.04473], [0.50000,-0.04405], [0.51309,-0.04334], [0.52617,-0.04260], [0.53923,-0.04183], [0.55226,-0.04103], [0.56526,-0.04021], [0.57822,-0.03937], [0.59112,-0.03850], [0.60396,-0.03762], [0.61672,-0.03671], [0.62941,-0.03579], [0.64201,-0.03485], [0.65451,-0.03391], [0.66690,-0.03294], [0.67918,-0.03197], [0.69134,-0.03099], [0.70337,-0.03000], [0.71526,-0.02901], [0.72700,-0.02801], [0.73858,-0.02701], [0.75000,-0.02600], [0.76125,-0.02500], [0.77232,-0.02400], [0.78320,-0.02300], [0.79389,-0.02200], [0.80438,-0.02101], [0.81466,-0.02003], [0.82472,-0.01906], [0.83457,-0.01809], [0.84418,-0.01714], [0.85355,-0.01620], [0.86269,-0.01527], [0.87157,-0.01436], [0.88020,-0.01346], [0.88857,-0.01259], [0.89668,-0.01173], [0.90451,-0.01089], [0.91206,-0.01008], [0.91934,-0.00929], [0.92632,-0.00852], [0.93301,-0.00778], [0.93941,-0.00706], [0.94550,-0.00638], [0.95129,-0.00572], [0.95677,-0.00509], [0.96194,-0.00450], [0.96679,-0.00394], [0.97132,-0.00341], [0.97553,-0.00292], [0.97941,-0.00246], [0.98296,-0.00204], [0.98618,-0.00166], [0.98907,-0.00131], [0.99163,-0.00101], [0.99384,-0.00074], [0.99572,-0.00052], [0.99726,-0.00033], [0.99846,-0.00019], [0.99931,-0.00008], [0.99983,-0.00002], [1.00000,0.00000]];

// RULING P5: draw the airfoil in the local XY plane, extrude a thin
// slab along local Z, then rotate the slab 90deg about X before
// translating into place. That maps the extrusion axis into world Y
// (span), not world Z -- verified to render span-in-Y, chord-in-X.
module section(chord, twist, x_le, y, z) {
    translate([x_le, y, z]) rotate([90,0,0]) linear_extrude(0.001)
        rotate([0,0,twist]) polygon(points=[for (p = airfoil) [p[0]*chord, p[1]*chord]]);
}

module tail_section(chord, twist, x_le, y, z) {
    translate([x_le, y, z]) rotate([90,0,0]) linear_extrude(0.001)
        rotate([0,0,twist]) polygon(points=[for (p = airfoil_tail) [p[0]*chord, p[1]*chord]]);
}
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

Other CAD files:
model_v2/argus7_v2.scad
model/argus7_model.scad
model_final/argus7_v4.scad

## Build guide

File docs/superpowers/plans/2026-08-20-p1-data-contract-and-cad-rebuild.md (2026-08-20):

# ARGUS-7 Phase P1 — Data Contract & CAD Rebuild Implementation Plan

> **For agentic workers:** REQUIRED SUB-SKILL: Use superpowers:subagent-driven-development (recommended) or superpowers:executing-plans to implement this plan task-by-task. Steps use checkbox (`- [ ]`) syntax for tracking.

**Goal:** Replace the defective `model/argus7_model.scad` with a parametric, airfoil-lofted, correctly-axed CAD model generated from a single validated parameter file, with closure guards that make the known geometry-drift failures unrepresentable.

**Architecture:** One YAML file is the sole source of truth. `geometry.py` derives every dependent quantity and asserts closure at load time. `cad/` builds a B-rep solid with build123d from those derived values and exports STEP + STL + a regenerated OpenSCAD file. No module hardcodes geometry; no header comment is hand-written.

**Tech Stack:** Python 3.14, pydantic (schema), PyYAML, build123d/OCP (B-rep CAD), numpy, trimesh (mesh validation), pytest. Fallback `.venv-cad` on Python 3.12 if OCP wheels misbehave on 3.14.

**Spec:** `docs/superpowers/specs/2026-08-20-argus7-cad-sim-optimisation-design.md`

## Global Constraints

- **Axis convention (project-wide, never deviate):** `x` = aft along fuselage (nose at x=0, tail at +x); `y` = starboard span; `z` = up. This is the fix for Defect 1 and every module assumes it.
- **Single source of truth:** geometry lives only in `design/*.yaml`. Any module that hardcodes a chord, span, area or MAC is a defect.
- **Generated files carry generated headers.** Header comments in `.scad`/`.step` output are emitted from the loaded parameters, never typed by hand.
- **Closure tolerance:** 1e-9 relative on all derived-geometry identities.
- **Units:** SI throughout — metres, kilograms, radians internally; degrees only at the YAML boundary, converted on load.
- **v1.0 parameters are transcribed as published**, including the §2 tail inconsistency. Corrections happen in v2, never by silently editing v1.

---

### Task 1: Design schema, parameter file, and closure guards

This is the structural fix for Defect 2. Everything downstream depends on it.

**Files:**
- Create: `argus7/__init__.py`, `argus7/design/__init__.py`
- Create: `argus7/design/schema.py`
- Create: `argus7/design/geometry.py`
- Create: `design/argus7_v1.yaml`
- Test: `tests/test_geometry_closure.py`

**Interfaces:**
- Consumes: nothing (foundation task)
- Produces:
  - `load_design(path: str | Path) -> Design` — pydantic model, raises `ClosureError` on inconsistency
  - `Design.wing` with fields `area_m2, aspect_ratio, taper_ratio, airfoil, twist_tip_deg, dihedral_deg, sweep_le_deg, thickness_ratio, incidence_deg`
  - `WingGeometry` dataclass with `span_m, chord_root_m, chord_tip_m, mac_m, mac_y_m, area_m2, aspect_ratio`
  - `derive_wing(wing) -> WingGeometry`
  - `tail_volume_h(design) -> float`
  - `ClosureError(Exception)`

- [ ] **Step 1: Write the failing tests**

```python
# tests/test_geometry_closure.py
import math
import pytest
from argus7.design.geometry import derive_wing, tail_volume_h, ClosureError
from argus7.design.schema import load_design

REPORT = dict(span=9.263, c_root=0.5807, c_tip=0.2613, mac=0.4412)  # report §2

def test_v1_matches_report_section_2():
    """Regression guard for Defect 2: the superseded Gemini chords must never return."""
    g = derive_wing(load_design("design/argus7_v1.yaml").wing)
    assert g.span_m       == pytest.approx(REPORT["span"],   abs=1e-3)
    assert g.chord_root_m == pytest.approx(REPORT["c_root"], abs=1e-3)
    assert g.chord_tip_m  == pytest.approx(REPORT["c_tip"],  abs=1e-3)
    assert g.mac_m        == pytest.approx(REPORT["mac"],    abs=1e-3)

def test_superseded_gemini_chords_are_rejected():
    """c_root=0.674 implies S=4.525 and AR=19.0 - must not validate against S=3.9/AR=22."""
    g = derive_wing(load_design("design/argus7_v1.yaml").wing)
    assert abs(g.chord_root_m - 0.674) > 0.05

def test_closure_identities_hold():
    g = derive_wing(load_design("design/argus7_v1.yaml").wing)
    assert abs(g.area_m2 - (g.span_m / 2) * (g.chord_root_m + g.chord_tip_m)) < 1e-9
    assert abs(g.aspect_ratio - g.span_m**2 / g.area_m2) < 1e-9

def test_inconsistent_design_raises(tmp_path):
    """A YAML asserting a chord that contradicts S/AR/taper must fail loudly."""
    bad = tmp_path / "bad.yaml"
    bad.write_text(
        "name: bad\nvariant: test\n"
        "wing: {area_m2: 3.9, aspect_ratio: 22.0, taper_ratio: 0.45,\n"
        "       chord_root_m_assert: 0.674, airfoil: FX63-137, twist_tip_deg: -3.0,\n"
        "       dihedral_deg: 3.0, sweep_le_deg: 1.0, thickness_ratio: 0.137, incidence_deg: 2.0}\n"
    )
    with pytest.raises(ClosureError):
        load_design(bad)

@pytest.mark.xfail(reason=(
    "Report section 2 tail row does not close: S_h=0.31 m2 with arm=3.2 m gives "
    "V_h=0.577, not the stated 0.68 (17.9% discrepancy). Either S_h should be "
    "0.366 m2 or V_h is 0.577. Transcribed as published; resolved in v2, not by "
    "silently editing v1."))
def test_report_stated_tail_volume():
    assert tail_volume_h(load_design("design/argus7_v1.yaml")) == pytest.approx(0.68, abs=0.005)

def test_tail_volume_actual_value_is_pinned():
    """Pin the real computed value so a future edit cannot drift it unnoticed."""
    assert tail_volume_h(load_design("design/argus7_v1.yaml")) == pytest.approx(0.5765, abs=1e-3)
```

- [ ] **Step 2: Run tests to verify they fail**

Run: `.venv/bin/pytest tests/test_geometry_closure.py -v`
Expected: FAIL — `ModuleNotFoundError: No module named 'argus7'`

- [ ] **Step 3: Write the schema**

```python
# argus7/design/schema.py
from __future__ import annotations
from pathlib import Path
import yaml
from pydantic import BaseModel, Field

class Wing(BaseModel):
    area_m2: float = Field(gt=0)
    aspect_ratio: float = Field(gt=0)
    taper_ratio: float = Field(gt=0, le=1)
    airfoil: str
    twist_tip_deg: float          # negative = washout
    dihedral_deg: float
    sweep_le_deg: float
    thickness_ratio: float = Field(gt=0, lt=0.5)
    incidence_deg: float
    chord_root_m_assert: float | None = None   # optional cross-check, not a source of truth

class Fuselage(BaseModel):
    length_m: float = Field(gt=0)
    max_diameter_m: float = Field(gt=0)

class Booms(BaseModel):
    length_m: float = Field(gt=0)
    diameter_m: float = Field(gt=0)
    y_station_frac: float = Field(gt=0, lt=1)

class Tail(BaseModel):
    type: str
    area_h_m2: float = Field(gt=0)
    arm_m: float = Field(gt=0)
    dihedral_deg: float
    taper_ratio: float = Field(gt=0, le=1)
    airfoil: str

class Propulsion(BaseModel):
    engine_displacement_cc: float
    power_max_kw: float
    reduction_ratio: float
    prop_diameter_m: float
    prop_rpm: float

class Masses(BaseModel):
    airframe: float; powertrain: float; avionics: float
    recovery: float; payload: float; fuel: float; mtow: float

class Mission(BaseModel):
    payload_mass_kg: float
    payload_power_w: float
    loiter_altitude_m: float

class Aero(BaseModel):
    cd0: float; oswald_e: float; cl_max: float

class Design(BaseModel):
    name: str
    variant: str
    wing: Wing
    fuselage: Fuselage | None = None
    booms: Booms | None = None
    tail: Tail | None = None
    propulsion: Propulsion | None = None
    masses: Masses | None = None
    mission: Mission | None = None
    aero: Aero | None = None

def load_design(path: str | Path) -> Design:
    from argus7.design.geometry import check_closure
    data = yaml.safe_load(Path(path).read_text())
    design = Design(**data)
    check_closure(design)
    return design
```

- [ ] **Step 4: Write the geometry derivation and closure guard**

```python
# argus7/design/geometry.py
from __future__ import annotations
import math
from dataclasses import dataclass

TOL = 1e-9

class ClosureError(Exception):
    """Raised when a design's stated geometry contradicts its derived geometry."""

@dataclass(frozen=True)
class WingGeometry:
    span_m: float
    chord_root_m: float
    chord_tip_m: float
    mac_m: float
    mac_y_m: float          # spanwise station of the MAC
    area_m2: float
    aspect_ratio: float

def derive_wing(wing) -> WingGeometry:
    S, AR, lam = wing.area_m2, wing.aspect_ratio, wing.taper_ratio
    b  = math.sqrt(AR * S)
    cr = S / ((b / 2.0) * (1.0 + lam))
    ct = lam * cr
    mac = (2.0 / 3.0) * cr * (1.0 + lam + lam**2) / (1.0 + lam)
    mac_y = (b / 6.0) * (1.0 + 2.0 * lam) / (1.0 + lam)
    return WingGeometry(b, cr, ct, mac, mac_y, S, AR)

def tail_volume_h(design) -> float:
    """Horizontal tail volume coefficient V_h = S_h * l_h / (S_w * MAC)."""
    g = derive_wing(design.wing)
    return design.tail.area_h_m2 * design.tail.arm_m / (g.area_m2 * g.mac_m)

def check_closure(design) -> None:
    g = derive_wing(design.wing)
    identities = {
        "S = (b/2)(c_root + c_tip)": g.area_m2 - (g.span_m / 2) * (g.chord_root_m + g.chord_tip_m),
        "AR = b^2 / S":              g.aspect_ratio - g.span_m**2 / g.area_m2,
        "c_tip = taper * c_root":    g.chord_tip_m - design.wing.taper_ratio * g.chord_root_m,
    }
    for name, residual in identities.items():
        if abs(residual) > TOL:
            raise ClosureError(f"{name} violated by {residual:.3e}")
    assert_ = design.wing.chord_root_m_assert
    if assert_ is not None and abs(assert_ - g.chord_root_m) > 1e-3:
        raise ClosureError(
            f"stated chord_root_m_assert={assert_:.4f} contradicts derived "
            f"{g.chord_root_m:.4f} from S={g.area_m2}, AR={g.aspect_ratio}, "
            f"taper={design.wing.taper_ratio}")
```

- [ ] **Step 5: Write the v1.0 parameter file**

```yaml
# design/argus7_v1.yaml
# ARGUS-7 v1.0 as published in docs/argus7_design_report.md section 2.
# Transcribed verbatim including the section-2 tail inconsistency (see
# tests/test_geometry_closure.py::test_report_stated_tail_volume).
name: ARGUS-7
variant: v1.0

mission:
  payload_mass_kg: 50.0
  payload_power_w: 500.0
  loiter_altitude_m: 4000.0

wing:
  area_m2: 3.9
  aspect_ratio: 22.0
  taper_ratio: 0.45
  airfoil: FX63-137
  twist_tip_deg: -3.0
  dihedral_deg: 3.0
  sweep_le_deg: 1.0
  thickness_ratio: 0.137
  incidence_deg: 2.0

fuselage: {length_m: 3.4, max_diameter_m: 0.48}
booms:    {length_m: 3.2, diameter_m: 0.09, y_station_frac: 0.134}
tail:     {type: inverted_v, area_h_m2: 0.31, arm_m: 3.2,
           dihedral_deg: -42.0, taper_ratio: 0.55, airfoil: NACA0010}
propulsion: {engine_displacement_cc: 250.0, power_max_kw: 17.0,
             reduction_ratio: 2.3, prop_diameter_m: 0.813, prop_rpm: 2100.0}
masses:   {airframe: 60.5, powertrain: 25.0, avionics: 6.0, recovery: 7.0,
           payload: 50.0, fuel: 101.5, mtow: 250.0}
aero:     {cd0: 0.020, oswald_e: 0.85, cl_max: 1.6}
```

- [ ] **Step 6: Run tests to verify they pass**

Run: `.venv/bin/pytest tests/test_geometry_closure.py -v`
Expected: 5 PASSED, 1 XFAIL (the documented report §2 tail discrepancy)

- [ ] **Step 7: Commit**

```bash
git add argus7/ design/ tests/test_geometry_closure.py
git commit -m "feat(design): parameter schema with geometry closure guards

Single source of truth for all geometry. Closure assertions make the
superseded-chord regression (Defect 2) unrepresentable. Documents the
report section-2 tail volume discrepancy as an xfail rather than
silently picking a value."
```

---

### Task 2: Airfoil coordinate library

**Files:**
- Create: `argus7/cad/__init__.py`, `argus7/cad/airfoil_coords.py`
- Create: `data/airfoils/fx63137.dat`, `data/airfoils/naca0010.dat`
- Test: `tests/test_airfoil_coords.py`

**Interfaces:**
- Consumes: nothing
- Produces:
  - `load_airfoil(name: str) -> np.ndarray` — (N,2) array, Selig order (TE→upper→LE→lower→TE), x normalised 0..1
  - `naca4(code: str, n: int = 121) -> np.ndarray`
  - `scale_airfoil(coords, chord, twist_rad, le_pos) -> np.ndarray` — (N,3) points in the project frame
  - `max_thickness(coords) -> float`

- [ ] **Step 1: Write the failing tests**

```python
# tests/test_airfoil_coords.py
import numpy as np, pytest
from argus7.cad.airfoil_coords import load_airfoil, naca4, max_thickness, scale_airfoil

def test_naca0010_thickness_is_10_percent():
    assert max_thickness(naca4("0010")) == pytest.approx(0.10, abs=0.002)

def test_naca0012_thickness_is_12_percent():
    assert max_thickness(naca4("0012")) == pytest.approx(0.12, abs=0.002)

def test_naca0010_is_symmetric():
    c = naca4("0010")
    assert abs(c[:, 1].max() + c[:, 1].min()) < 1e-6

def test_fx63137_thickness_matches_its_name():
    """FX 63-137 is 13.7% thick by designation."""
    assert max_thickness(load_airfoil("fx63137")) == pytest.approx(0.137, abs=0.005)

def test_coordinates_are_normalised():
    c = load_airfoil("fx63137")
    assert c[:, 0].min() == pytest.approx(0.0, abs=1e-6)
    assert c[:, 0].max() == pytest.approx(1.0, abs=1e-6)

def test_scale_airfoil_applies_chord_and_twist():
    c = naca4("0010")
    out = scale_airfoil(c, chord=0.5, twist_rad=0.0, le_pos=(1.0, 2.0, 0.3))
    assert out.shape[1] == 3
    # chord runs aft along +x from the leading edge
    assert out[:, 0].max() - out[:, 0].min() == pytest.approx(0.5, abs=1e-6)
    assert out[:, 1].min() == pytest.approx(2.0, abs=1e-6)  # constant span station

def test_twist_rotates_about_leading_edge():
    c = naca4("0010")
    a = scale_airfoil(c, 1.0, 0.0, (0.0, 0.0, 0.0))
    b = scale_airfoil(c, 1.0, np.deg2rad(-3.0), (0.0, 0.0, 0.0))
    assert b[:, 2].max() != pytest.approx(a[:, 2].max(), abs=1e-6)
    # leading edge is the pivot and must not move
    le_a, le_b = a[np.argmin(a[:, 0])], b[np.argmin(b[:, 0])]
    assert np.allclose(le_a, le_b, atol=1e-6)
```

- [ ] **Step 2: Run tests to verify they fail**

Run: `.venv/bin/pytest tests/test_airfoil_coords.py -v`
Expected: FAIL — `ModuleNotFoundError: No module named 'argus7.cad'`

- [ ] **Step 3: Implement the coordinate library**

```python
# argus7/cad/airfoil_coords.py
from __future__ import annotations
from pathlib import Path
import numpy as np

DATA = Path(__file__).resolve().parents[2] / "data" / "airfoils"

def naca4(code: str, n: int = 121) -> np.ndarray:
    """4-digit NACA section in Selig order (TE -> upper -> LE -> lower -> TE)."""
    m, p, t = int(code[0]) / 100.0, int(code[1]) / 10.0, int(code[2:]) / 100.0
    beta = np.linspace(0.0, np.pi, n)
    x = (1 - np.cos(beta)) / 2.0                       # cosine clustering at LE/TE
    yt = 5 * t * (0.2969*np.sqrt(x) - 0.1260*x - 0.3516*x**2
                  + 0.2843*x**3 - 0.1036*x**4)         # closed-TE coefficient
    if m == 0.0:
        yc, dyc = np.zeros_like(x), np.zeros_like(x)
    else:
        yc = np.where(x < p, m/p**2*(2*p*x - x**2), m/(1-p)**2*((1-2*p) + 2*p*x - x**2))
        dyc = np.where(x < p, 2*m/p**2*(p - x), 2*m/(1-p)**2*(p - x))
    th = np.arctan(dyc)
    xu, yu = x - yt*np.sin(th), yc + yt*np.cos(th)
    xl, yl = x + yt*np.sin(th), yc - yt*np.cos(th)
    upper = np.column_stack([xu, yu])[::-1]            # TE -> LE
    lower = np.column_stack([xl, yl])[1:]              # LE -> TE
    return np.vstack([upper, lower])

def load_airfoil(name: str) -> np.ndarray:
    """Load a Selig-format .dat file, skipping the title line, and normalise x to 0..1."""
    path = DATA / f"{name.lower().replace('-', '').replace(' ', '')}.dat"
    rows = []
    for line in path.read_text().splitlines():
        parts = line.split()
        if len(parts) != 2:
            continue
        try:
            rows.append((float(parts[0]), float(parts[1])))
        except ValueError:
            continue                                    # title or header line
    c = np.array(rows)
    x0, x1 = c[:, 0].min(), c[:, 0].max()
    c[:, 0] = (c[:, 0] - x0) / (x1 - x0)
    c[:, 1] = c[:, 1] / (x1 - x0)
    return c

def max_thickness(coords: np.ndarray) -> float:
    """Max thickness/chord, measured by interpolating upper and lower surfaces."""
    le = int(np.argmin(coords[:, 0]))
    upper, lower = coords[:le + 1][::-1], coords[le:]
    xs = np.linspace(0.0, 1.0, 400)
    yu = np.interp(xs, upper[:, 0], upper[:, 1])
    yl = np.interp(xs, lower[:, 0], lower[:, 1])
    return float(np.max(yu - yl))

def scale_airfoil(coords: np.ndarray, chord: float, twist_rad: float,
                  le_pos: tuple[float, float, float]) -> np.ndarray:
    """Place a normalised section in the project frame.

    Project frame: x aft, y starboard, z up. The section is scaled by `chord`,
    rotated by `twist_rad` about the leading edge (negative = washout, nose down),
    and translated so its leading edge sits at `le_pos`.
    """
    xc, zc = coords[:, 0] * chord, coords[:, 1] * chord
    ct, st = np.cos(twist_rad), np.sin(twist_rad)
    xr = xc * ct - zc * st
    zr = xc * st + zc * ct
    x0, y0, z0 = le_pos
    return np.column_stack([xr + x0, np.full_like(xr, y0), zr + z0])
```

- [ ] **Step 4: Fetch the FX 63-137 coordinates**

```bash
mkdir -p data/airfoils
curl -sS "https://m-selig.ae.illinois.edu/ads/coord/fx63137.dat" -o data/airfoils/fx63137.dat
head -3 data/airfoils/fx63137.dat
.venv/bin/python -c "
from argus7.cad.airfoil_coords import load_airfoil, max_thickness
print('t/c =', max_thickness(load_airfoil('fx63137')))"
```

Expected: `t/c ≈ 0.137`. If the UIUC fetch fails, generate a placeholder with
`naca4('4413')` (similar camber and thickness class), record the substitution in
`data/airfoils/README.md`, and open it as a known gap — do **not** silently
substitute without recording it.

- [ ] **Step 5: Run tests to verify they pass**

Run: `.venv/bin/pytest tests/test_airfoil_coords.py -v`
Expected: 7 PASSED

- [ ] **Step 6: Commit**

```bash
git add argus7/cad/ data/airfoils/ tests/test_airfoil_coords.py
git commit -m "feat(cad): airfoil coordinate library with NACA4 generator

Real section coordinates replace the sphere-hull massing that stood in
for an airfoil (Defect 3). Twist rotates about the leading edge."
```

---

### Task 3: Lofted wing solid

**Files:**
- Create: `argus7/cad/model.py`
- Test: `tests/test_cad_wing.py`

**Interfaces:**
- Consumes: `load_design`, `derive_wing` (Task 1); `load_airfoil`, `naca4`, `scale_airfoil` (Task 2)
- Produces:
  - `build_wing(design, n_sections: int = 9) -> build123d.Part` — full wing, both halves, origin at wing root leading edge
  - `section_stations(design, n) -> list[tuple[float, float, float, float]]` — `(y, chord, twist_rad, x_le)` per station

- [ ] **Step 1: Write the failing tests**

```python
# tests/test_cad_wing.py
import math, pytest
from argus7.design.schema import load_design
from argus7.design.geometry import derive_wing
from argus7.cad.model import build_wing, section_stations

@pytest.fixture(scope="module")
def design(): return load_design("design/argus7_v1.yaml")

@pytest.fixture(scope="module")
def wing(design): return build_wing(design)

def test_wing_spans_along_y_not_x(wing, design):
    """REGRESSION GUARD FOR DEFECT 1: the wing must span across the airframe,
    not along it. The original SCAD spanned the wing along the fuselage axis."""
    bb = wing.bounding_box()
    span_extent  = bb.max.Y - bb.min.Y
    chord_extent = bb.max.X - bb.min.X
    assert span_extent > 8.0, f"wing spans only {span_extent:.2f} m in y"
    assert span_extent > 5 * chord_extent, "wing is not spanwise-dominant in y"

def test_wing_span_matches_derived_geometry(wing, design):
    g = derive_wing(design.wing)
    bb = wing.bounding_box()
    assert (bb.max.Y - bb.min.Y) == pytest.approx(g.span_m, rel=0.02)

def test_wing_is_symmetric_about_centreline(wing):
    bb = wing.bounding_box()
    assert bb.max.Y == pytest.approx(-bb.min.Y, abs=1e-3)

def test_wing_planform_area_matches_spec(wing, design):
    """Loft volume / span / mean-thickness should recover S within meshing tolerance."""
    g = derive_wing(design.wing)
    approx_area = wing.volume / (0.68 * design.wing.thickness_ratio * g.mac_m)
    assert approx_area == pytest.approx(g.area_m2, rel=0.15)

def test_wing_solid_is_valid(wing):
    assert wing.is_valid()
    assert wing.volume > 0

def test_stations_apply_linear_taper_and_washout(design):
    g = derive_wing(design.wing)
    st = section_stations(design, 9)
    root, tip = st[0], st[-1]
    assert root[1] == pytest.approx(g.chord_root_m, rel=1e-6)
    assert tip[1]  == pytest.approx(g.chord_tip_m,  rel=1e-6)
    assert root[2] == pytest.approx(0.0, abs=1e-9)
    assert tip[2]  == pytest.approx(math.radians(design.wing.twist_tip_deg), rel=1e-6)

def test_dihedral_raises_the_tip(design, wing):
    bb = wing.bounding_box()
    g = derive_wing(design.wing)
    expected_rise = (g.span_m / 2) * math.tan(math.radians(design.wing.dihedral_deg))
    assert bb.max.Z > 0.5 * expected_rise
```

- [ ] **Step 2: Run tests to verify they fail**

Run: `.venv/bin/pytest tests/test_cad_wing.py -v`
Expected: FAIL — `ImportError: cannot import name 'build_wing'`

- [ ] **Step 3: Implement the wing loft**

```python
# argus7/cad/model.py
from __future__ import annotations
import math
import numpy as np
from build123d import Part, Polyline, make_face, loft, Plane, Vector

from argus7.design.geometry import derive_wing
from argus7.cad.airfoil_coords import load_airfoil, naca4, scale_airfoil

def _section_coords(name: str) -> np.ndarray:
    return naca4(name[4:]) if name.upper().startswith("NACA") else load_airfoil(name)

def section_stations(design, n: int = 9):
    """(y, chord, twist_rad, x_le) at n stations from root to tip."""
    g = derive_wing(design.wing)
    semi = g.span_m / 2.0
    sweep = math.radians(design.wing.sweep_le_deg)
    out = []
    for i in range(n):
        f = i / (n - 1)                                  # 0 at root, 1 at tip
        y = f * semi
        chord = g.chord_root_m + f * (g.chord_tip_m - g.chord_root_m)
        twist = f * math.radians(design.wing.twist_tip_deg)
        x_le = y * math.tan(sweep)
        out.append((y, chord, twist, x_le))
    return out

def _section_face(design, y, chord, twist, x_le, dihedral_rad, coords):
    z = y * math.tan(dihedral_rad)
    pts = scale_airfoil(coords, chord, twist, (x_le, y, z))
    verts = [Vector(*p) for p in pts]
    if (verts[0] - verts[-1]).length > 1e-9:
        verts.append(verts[0])                            # close the section
    return make_face(Polyline(*verts))

def build_wing(design, n_sections: int = 9) -> Part:
    """Full wing, both halves, lofted through real airfoil sections.

    Origin is the root leading edge. x aft, y starboard, z up.
    """
    coords = _section_coords(design.wing.airfoil)
    dihedral = math.radians(design.wing.dihedral_deg)
    faces = [_section_face(design, y, c, t, x, dihedral, coords)
             for (y, c, t, x) in section_stations(design, n_sections)]
    starboard = loft(faces)
    port = starboard.mirror(Plane.XZ)
    return starboard + port
```

- [ ] **Step 4: Run tests to verify they pass**

Run: `.venv/bin/pytest tests/test_cad_wing.py -v`
Expected: 7 PASSED

If `loft` rejects the section wires, reduce `n_sections` to 5 and confirm the
sections are planar and consistently oriented before increasing again.

- [ ] **Step 5: Commit**

```bash
git add argus7/cad/model.py tests/test_cad_wing.py
git commit -m "feat(cad): lofted wing with real sections, twist and dihedral

Includes the Defect 1 regression guard: the wing must span along y and
be spanwise-dominant, which the original SCAD model was not."
```

---

### Task 4: Fuselage, booms, inverted-V tail and installed items

**Files:**
- Modify: `argus7/cad/model.py`
- Test: `tests/test_cad_airframe.py`

**Interfaces:**
- Consumes: `build_wing`, `section_stations` (Task 3)
- Produces:
  - `build_fuselage(design) -> Part`
  - `build_booms(design) -> Part`
  - `build_tail(design) -> Part`
  - `build_installed_items(design) -> Part` — EO/IR gimbal ball, parachute bay, prop disc, antenna blade
  - `build_aircraft(design) -> Part` — the assembled model

- [ ] **Step 1: Write the failing tests**

```python
# tests/test_cad_airframe.py
import pytest
from argus7.design.schema import load_design
from argus7.design.geometry import derive_wing
from argus7.cad.model import build_fuselage, build_booms, build_tail, build_aircraft

@pytest.fixture(scope="module")
def design(): return load_design("design/argus7_v1.yaml")

def test_fuselage_runs_along_x(design):
    """REGRESSION GUARD FOR DEFECT 1, other half: the fuselage must be the
    long axis in x while the wing is long in y. In the original SCAD both
    ran along y."""
    bb = build_fuselage(design).bounding_box()
    length = bb.max.X - bb.min.X
    width  = bb.max.Y - bb.min.Y
    assert length == pytest.approx(design.fuselage.length_m, rel=0.05)
    assert length > 4 * width

def test_wing_and_fuselage_axes_are_perpendicular(design):
    """The precise defect: wing long axis and fuselage long axis must differ."""
    fus = build_fuselage(design).bounding_box()
    from argus7.cad.model import build_wing
    wing = build_wing(design).bounding_box()
    fus_long  = "X" if (fus.max.X - fus.min.X) > (fus.max.Y - fus.min.Y) else "Y"
    wing_long = "X" if (wing.max.X - wing.min.X) > (wing.max.Y - wing.min.Y) else "Y"
    assert fus_long == "X" and wing_long == "Y"

def test_booms_are_spaced_in_y_and_run_along_x(design):
    bb = build_booms(design).bounding_box()
    g = derive_wing(design.wing)
    expected_sep = 2 * design.booms.y_station_frac * (g.span_m / 2)
    assert (bb.max.Y - bb.min.Y) == pytest.approx(expected_sep, rel=0.2)
    assert (bb.max.X - bb.min.X) == pytest.approx(design.booms.length_m, rel=0.15)

def test_tail_sits_aft_of_the_wing(design):
    assert build_tail(design).bounding_box().min.X > 0.5 * design.tail.arm_m

def test_inverted_v_tail_dips_below_boom_line(design):
    """Inverted V means the panels angle downward from the boom."""
    assert build_tail(design).bounding_box().min.Z < 0.0

def test_full_aircraft_is_valid_and_within_envelope(design):
    ac = build_aircraft(design)
    g = derive_wing(design.wing)
    bb = ac.bounding_box()
    assert ac.is_valid()
    assert (bb.max.Y - bb.min.Y) == pytest.approx(g.span_m, rel=0.03)
    assert (bb.max.X - bb.min.X) < 1.5 * design.fuselage.length_m + design.tail.arm_m
```

- [ ] **Step 2: Run tests to verify they fail**

Run: `.venv/bin/pytest tests/test_cad_airframe.py -v`
Expected: FAIL — `ImportError: cannot import name 'build_fuselage'`

- [ ] **Step 3: Implement the airframe components**

```python
# append to argus7/cad/model.py
from build123d import Cylinder, Sphere, Box, Location, Rotation, Axis

def build_fuselage(design) -> Part:
    """Pod along +x: nose at x=0, engine/prop end at x=length. Lofted from
    circular stations so it is a true solid of revolution class, not a sphere hull."""
    L, R = design.fuselage.length_m, design.fuselage.max_diameter_m / 2.0
    # (x_fraction, radius_fraction) - nose, max section, aft taper to engine
    stations = [(0.00, 0.15), (0.08, 0.62), (0.22, 1.00), (0.55, 0.96),
                (0.80, 0.70), (1.00, 0.34)]
    faces = []
    for xf, rf in stations:
        pl = Plane(origin=(xf * L, 0, 0), z_dir=(1, 0, 0))
        faces.append(pl * make_face(pl.location * Circle(max(rf * R, 1e-3)).wire()))
    return loft(faces)

def build_booms(design) -> Part:
    """Twin booms: spaced in y, running along x, carrying the tail."""
    g = derive_wing(design.wing)
    y = design.booms.y_station_frac * (g.span_m / 2.0)
    r = design.booms.diameter_m / 2.0
    L = design.booms.length_m
    x0 = -0.25 * L                                       # boom starts ahead of the wing
    boom = Cylinder(radius=r, height=L, rotation=(0, 90, 0))
    starboard = Location((x0 + L / 2, y, 0)) * boom
    port      = Location((x0 + L / 2, -y, 0)) * boom
    return starboard + port

def build_tail(design) -> Part:
    """Inverted-V tail: two panels angled downward from the boom ends.

    area_h_m2 is the projected horizontal area, so each panel's true area is
    S_h / (2 cos^2(dihedral)).
    """
    g = derive_wing(design.wing)
    y_boom = design.booms.y_station_frac * (g.span_m / 2.0)
    gam = math.radians(design.tail.dihedral_deg)          # negative = inverted
    panel_area = design.tail.area_h_m2 / (2.0 * math.cos(gam) ** 2)
    lam = design.tail.taper_ratio
    panel_span = math.sqrt(panel_area * 3.0)              # AR 3 tail panel
    c_root = 2 * panel_area / (panel_span * (1 + lam))
    coords = _section_coords(design.tail.airfoil)
    x_te = design.tail.arm_m
    parts = []
    for sgn in (+1, -1):
        faces = []
        for f in (0.0, 1.0):
            chord = c_root * (1 + f * (lam - 1))
            span_off = f * panel_span
            y = sgn * (y_boom + span_off * math.cos(gam))
            z = span_off * math.sin(gam)
            pts = scale_airfoil(coords, chord, 0.0, (x_te, y, z))
            verts = [Vector(*p) for p in pts]
            if (verts[0] - verts[-1]).length > 1e-9:
                verts.append(verts[0])
            faces.append(make_face(Polyline(*verts)))
        parts.append(loft(faces))
    return parts[0] + parts[1]

def build_installed_items(design) -> Part:
    """EO/IR gimbal, parachute bay hump, pusher prop disc, comms antenna blade."""
    L, R = design.fuselage.length_m, design.fuselage.max_diameter_m / 2.0
    gimbal = Location((0.55 * R + 0.30, 0, -R - 0.06)) * Sphere(0.15)
    chute  = Location((0.95, 0, R * 0.75)) * Sphere(0.14)
    d = design.propulsion.prop_diameter_m
    prop = Location((L + 0.06, 0, 0)) * Cylinder(radius=d / 2, height=0.02,
                                                 rotation=(0, 90, 0))
    ant = Location((1.45, 0, -R - 0.08)) * Box(0.18, 0.012, 0.14)
    return gimbal + chute + prop + ant

def build_aircraft(design) -> Part:
    """Assembled model. Wing root LE is placed at 22% of fuselage length."""
    wing = Location((0.22 * design.fuselage.length_m, 0, 0.05)) * build_wing(design)
    return wing + build_fuselage(design) + build_booms(design) \
                + build_tail(design) + build_installed_items(design)
```

Add `Circle` to the `build123d` import list at the top of the file.

- [ ] **Step 4: Run tests to verify they pass**

Run: `.venv/bin/pytest tests/test_cad_airframe.py -v`
Expected: 6 PASSED

- [ ] **Step 5: Commit**

```bash
git add argus7/cad/model.py tests/test_cad_airframe.py
git commit -m "feat(cad): fuselage, booms, inverted-V tail and installed items

Fuselage runs along x, wing spans y - the perpendicularity is now an
explicit test, closing Defect 1."
```

---

### Task 5: Export to STEP, STL and regenerated OpenSCAD

**Files:**
- Create: `argus7/cad/export.py`
- Create: `argus7/cad/to_openscad.py`
- Test: `tests/test_cad_export.py`

**Interfaces:**
- Consumes: `build_aircraft` (Task 4), `derive_wing` (Task 1)
- Produces:
  - `export_model(design, outdir: Path) -> dict[str, Path]` — writes `argus7.step`, `argus7.stl`, returns paths
  - `emit_openscad(design, path: Path) -> Path` — regenerated `.scad` with a **generated** header
  - `check_watertight(stl_path) -> bool`

- [ ] **Step 1: Write the failing tests**

```python
# tests/test_cad_export.py
import pytest, trimesh
from pathlib import Path
from argus7.design.schema import load_design
from argus7.design.geometry import derive_wing
from argus7.cad.export import export_model, check_watertight
from argus7.cad.to_openscad import emit_openscad

@pytest.fixture(scope="module")
def design(): return load_design("design/argus7_v1.yaml")

@pytest.fixture(scope="module")
def exported(design, tmp_path_factory):
    return export_model(design, tmp_path_factory.mktemp("cad"))

def test_step_and_stl_are_written(exported):
    assert exported["step"].exists() and exported["step"].stat().st_size > 10_000
    assert exported["stl"].exists()  and exported["stl"].stat().st_size > 10_000

def test_stl_is_watertight(exported):
    assert check_watertight(exported["stl"])

def test_stl_span_matches_design(exported, design):
    m = trimesh.load(exported["stl"])
    g = derive_wing(design.wing)
    assert (m.bounds[1][1] - m.bounds[0][1]) == pytest.approx(g.span_m, rel=0.03)

def test_openscad_header_is_generated_not_handwritten(design, tmp_path):
    """Defect 2 was a hand-typed header that drifted from the real geometry."""
    g = derive_wing(design.wing)
    text = emit_openscad(design, tmp_path / "m.scad").read_text()
    assert f"{g.mac_m:.4f}" in text
    assert f"{g.chord_root_m:.4f}" in text
    assert "0.674" not in text, "superseded Gemini root chord reappeared"
    assert "GENERATED" in text.upper()

def test_openscad_output_parses(design, tmp_path):
    import shutil, subprocess
    if shutil.which("openscad") is None:
        pytest.skip("openscad not installed")
    p = emit_openscad(design, tmp_path / "m.scad")
    r = subprocess.run(["openscad", "-o", str(tmp_path / "m.stl"), str(p)],
                       capture_output=True, timeout=300)
    assert r.returncode == 0, r.stderr.decode()[:2000]
```

- [ ] **Step 2: Run tests to verify they fail**

Run: `.venv/bin/pytest tests/test_cad_export.py -v`
Expected: FAIL — `ModuleNotFoundError: No module named 'argus7.cad.export'`

- [ ] **Step 3: Implement export and OpenSCAD emission**

```python
# argus7/cad/export.py
from __future__ import annotations
from pathlib import Path
import trimesh
from build123d import export_step, export_stl
from argus7.cad.model import build_aircraft

def export_model(design, outdir: str | Path) -> dict[str, Path]:
    outdir = Path(outdir); outdir.mkdir(parents=True, exist_ok=True)
    ac = build_aircraft(design)
    step, stl = outdir / "argus7.step", outdir / "argus7.stl"
    export_step(ac, str(step))
    export_stl(ac, str(stl), tolerance=1e-3, angular_tolerance=0.1)
    return {"step": step, "stl": stl}

def check_watertight(stl_path: str | Path) -> bool:
    m = trimesh.load(str(stl_path))
    return bool(m.is_watertight)
```

```python
# argus7/cad/to_openscad.py
from __future__ import annotations
import math
from pathlib import Path
from argus7.design.geometry import derive_wing
from argus7.cad.airfoil_coords import load_airfoil, naca4
from argus7.cad.model import section_stations, _section_coords

def emit_openscad(design, path: str | Path) -> Path:
    """Emit a viewable .scad whose header and geometry both come from the
    loaded design. Nothing here is hand-typed, which is what Defect 2 was."""
    g = derive_wing(design.wing)
    coords = _section_coords(design.wing.airfoil)
    poly = ", ".join(f"[{x:.5f},{y:.5f}]" for x, y in coords)
    lines = [
        "// ==== GENERATED FILE - DO NOT EDIT ====",
        f"// Generated by argus7.cad.to_openscad from design '{design.name}' "
        f"variant {design.variant}.",
        "// Edit design/*.yaml and regenerate. Hand-editing reintroduces the",
        "// geometry-drift defect this pipeline exists to prevent.",
        f"// S = {g.area_m2:.4f} m2 | AR = {g.aspect_ratio:.4f} | b = {g.span_m:.4f} m",
        f"// c_root = {g.chord_root_m:.4f} m | c_tip = {g.chord_tip_m:.4f} m "
        f"| MAC = {g.mac_m:.4f} m",
        "// Axes: x aft, y starboard, z up.",
        "$fn = 64;",
        f"airfoil = [{poly}];",
        "",
        "module section(chord, twist, x_le, y, z) {",
        "    translate([x_le, y, z]) rotate([0, -twist, 0])",
        "        linear_extrude(height=0.001)",
        "            polygon(points=[for (p = airfoil) [p[0]*chord, p[1]*chord]]);",
        "}",
        "",
        "module wing() {",
    ]
    stations = section_stations(design, 15)
    dih = math.radians(design.wing.dihedral_deg)
    for (y0, c0, t0, x0), (y1, c1, t1, x1) in zip(stations, stations[1:]):
        z0, z1 = y0 * math.tan(dih), y1 * math.tan(dih)
        for sgn in (1, -1):
            lines.append(
                f"    hull() {{ section({c0:.5f}, {math.degrees(t0):.4f}, {x0:.5f}, "
                f"{sgn * y0:.5f}, {z0:.5f});"
                f" section({c1:.5f}, {math.degrees(t1):.4f}, {x1:.5f}, "
                f"{sgn * y1:.5f}, {z1:.5f}); }}")
    L = design.fuselage.length_m
    R = design.fuselage.max_diameter_m / 2
    yb = design.booms.y_station_frac * (g.span_m / 2)
    lines += [
        "}",
        "",
        "module fuselage() {",
        f"    hull() {{ translate([{0.22*L:.4f},0,0]) sphere({R:.4f});",
        f"             translate([{0.80*L:.4f},0,0]) sphere({0.70*R:.4f});",
        f"             translate([{L:.4f},0,0]) sphere({0.34*R:.4f});",
        f"             translate([0.02,0,0]) sphere({0.15*R:.4f}); }}",
        "}",
        "",
        "module booms() {",
        f"    for (s = [1,-1]) translate([{-0.25*design.booms.length_m:.4f}, "
        f"s*{yb:.4f}, 0]) rotate([0,90,0]) "
        f"cylinder(d={design.booms.diameter_m:.4f}, h={design.booms.length_m:.4f});",
        "}",
        "",
        f"translate([{0.22*L:.4f}, 0, 0.05]) wing();",
        "fuselage();",
        "booms();",
    ]
    p = Path(path); p.write_text("\n".join(lines) + "\n")
    return p
```

- [ ] **Step 4: Run tests to verify they pass**

Run: `.venv/bin/pytest tests/test_cad_export.py -v`
Expected: 5 PASSED (the last may SKIP if `openscad` is absent)

- [ ] **Step 5: Commit**

```bash
git add argus7/cad/export.py argus7/cad/to_openscad.py tests/test_cad_export.py
git commit -m "feat(cad): STEP/STL export and generated OpenSCAD

The .scad header is emitted from loaded parameters, so it cannot drift
from the geometry it describes."
```

---

### Task 6: Replace the defective model, render, and document

**Files:**
- Create: `argus7/cad/render.py`
- Create: `scripts/build_model.py`
- Delete then regenerate: `model/argus7_model.scad`
- Modify: `README.md:60-75` (the "Known gaps" section)
- Test: `tests/test_regression_defects.py`

**Interfaces:**
- Consumes: everything above
- Produces:
  - `render_views(stl_path, outdir) -> list[Path]` — three-view + isometric PNGs
  - `scripts/build_model.py` — one command regenerating every CAD artifact

- [ ] **Step 1: Write the failing regression test**

```python
# tests/test_regression_defects.py
"""One test per defect found in the original model/argus7_model.scad.
These must never pass by accident again."""
import re, pytest
from pathlib import Path
from argus7.design.schema import load_design
from argus7.design.geometry import derive_wing

SCAD = Path("model/argus7_model.scad")

def test_defect2_superseded_chords_absent_from_committed_model():
    text = SCAD.read_text()
    assert "0.674" not in text, "superseded Gemini root chord is back"
    assert "0.303" not in text, "superseded Gemini tip chord is back"

def test_committed_model_matches_the_design_file():
    g = derive_wing(load_design("design/argus7_v1.yaml").wing)
    text = SCAD.read_text()
    assert f"{g.chord_root_m:.4f}" in text
    assert f"{g.mac_m:.4f}" in text

def test_defect3_model_contains_a_real_airfoil():
    text = SCAD.read_text()
    assert "airfoil = [" in text
    n = len(re.findall(r"\[-?\d+\.\d+,-?\d+\.\d+\]", text))
    assert n > 50, f"only {n} section coordinates - not a real airfoil"

def test_model_is_marked_generated():
    assert "GENERATED" in SCAD.read_text().upper()
```

- [ ] **Step 2: Run test to verify it fails**

Run: `.venv/bin/pytest tests/test_regression_defects.py -v`
Expected: FAIL — the committed `model/argus7_model.scad` still contains `0.674`

- [ ] **Step 3: Write the renderer and build script**

```python
# argus7/cad/render.py
from __future__ import annotations
import subprocess, shutil
from pathlib import Path

VIEWS = {"top": (0, 0, 0), "front": (90, 0, 0), "side": (90, 0, 90),
         "iso": (55, 0, 25)}

def render_views(scad_path: str | Path, outdir: str | Path) -> list[Path]:
    """Render orthographic views with OpenSCAD's headless camera."""
    if shutil.which("openscad") is None:
        raise RuntimeError("openscad not installed - run scripts/setup_env.sh")
    outdir = Path(outdir); outdir.mkdir(parents=True, exist_ok=True)
    out = []
    for name, (rx, ry, rz) in VIEWS.items():
        png = outdir / f"argus7_{name}.png"
        subprocess.run(
            ["openscad", "--autocenter", "--viewall", "--imgsize=1600,1200",
             f"--camera=0,0,0,{rx},{ry},{rz},0", "-o", str(png), str(scad_path)],
            check=True, capture_output=True, timeout=600)
        out.append(png)
    return out
```

```python
# scripts/build_model.py
"""Regenerate every CAD artifact from design/argus7_v1.yaml."""
from pathlib import Path
from argus7.design.schema import load_design
from argus7.cad.export import export_model, check_watertight
from argus7.cad.to_openscad import emit_openscad
from argus7.cad.render import render_views

def main(design_path="design/argus7_v1.yaml"):
    design = load_design(design_path)
    paths = export_model(design, Path("model"))
    scad = emit_openscad(design, Path("model/argus7_model.scad"))
    print(f"STEP {paths['step']}\nSTL  {paths['stl']}\nSCAD {scad}")
    print(f"watertight: {check_watertight(paths['stl'])}")
    for p in render_views(scad, Path("figures/cad")):
        print(f"render {p}")

if __name__ == "__main__":
    main()
```

- [ ] **Step 4: Regenerate the model and run the regression tests**

```bash
.venv/bin/python scripts/build_model.py
.venv/bin/pytest tests/test_regression_defects.py -v
```

Expected: 4 PASSED. `model/argus7_model.scad` is now generated, carries real
airfoil coordinates, and contains no superseded chord values.

- [ ] **Step 5: Run the whole suite**

Run: `.venv/bin/pytest tests/ -v`
Expected: all PASS, exactly 1 XFAIL (the documented report §2 tail discrepancy)

- [ ] **Step 6: Update the README "Known gaps" section**

Replace the first two bullets of `README.md`'s "Known gaps" with:

```markdown
- The CAD model is generated from `design/argus7_v1.yaml` by
  `scripts/build_model.py`. Do not hand-edit `model/argus7_model.scad` — it is
  overwritten on every build, and hand-editing is what caused the original
  geometry drift.
- **Report §2 tail row does not close:** S_h = 0.31 m² with arm 3.2 m gives
  V_h = 0.577, not the stated 0.68 (17.9% off). Either S_h should be 0.366 m²
  or V_h is 0.577. Tracked as an xfail in
  `tests/test_geometry_closure.py::test_report_stated_tail_volume`, to be
  resolved in v2 rather than by silently editing v1.
```

- [ ] **Step 7: Commit**

```bash
git add argus7/cad/render.py scripts/build_model.py model/ figures/cad/ \
        README.md tests/test_regression_defects.py
git commit -m "feat(cad): regenerate model from design file, retire hand-edited SCAD

Replaces the defective hand-written model. All four defects now carry
regression tests: wing/fuselage axis collision, superseded chords,
missing airfoil, and hand-written headers."
```

---

## Self-Review

**Spec coverage.** §5 data contract → Task 1. §6.4/§10 `cad/` → Tasks 2–6. Global
constraint "generated headers" → Tasks 5–6. Defects 1/2/3 from spec §1 → regression
tests in Tasks 3, 4 and 6. The report §2 tail discrepancy discovered during planning
→ Task 1 xfail plus README entry. Spec §6.1–6.3 (aero, prop, struct), §7
(optimisation) and §9 (gauntlet) are **out of scope for P1 by design** — they are
phases P2–P5 and get their own plans.

**Placeholder scan.** No TBD/TODO. Every code step carries runnable code. The one
conditional branch (UIUC fetch failure in Task 2 Step 4) specifies the exact
fallback and requires recording it rather than silently substituting.

**Type consistency.** `load_design` returns `Design` (Task 1) and is consumed under
that name in Tasks 3–6. `derive_wing` returns `WingGeometry` with `span_m`,
`chord_root_m`, `chord_tip_m`, `mac_m` — used consistently throughout.
`section_stations` returns `(y, chord, twist_rad, x_le)` in Task 3 and is unpacked
in that order in Tasks 4 and 5. `_section_coords` is defined in Task 3 and imported
by `to_openscad` in Task 5. `export_model` returns `dict[str, Path]` keyed
`"step"`/`"stl"`, matching its use in Tasks 5 and 6.

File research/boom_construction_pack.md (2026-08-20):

# ARGUS-7 — TAIL BOOM CONSTRUCTION DATA PACK

**Date:** 2026-08-20 · **Scope:** the two tail booms of the 250 kg MTOW / 9.26 m span configuration — construction method, layup, diameter, joints and fatigue life · **Companion to:** `research/materials_pack.md` (§4 boom sizing, §7 adhesives, §6.8 endurance ledger), `docs/argus7_design_report.md` §3/§5, `design/argus7_v1.yaml`

**The question this pack was written to answer:** the sponsor proposes a thin aluminium tube wrapped in carbon and vacuum-bagged. Does the aluminium earn its mass, how thick does the carbon actually need to be for *this* load case, and does hand-laying beat buying?

---

## 0. How to read this

Provenance tags are the same as `materials_pack.md`:

| Tag | Meaning |
|---|---|
| **[DS]** | Manufacturer datasheet, quoted verbatim (unit-converted only) |
| **[M]** | Measured / published experimental data |
| **[CALC]** | Computed here from the report's own geometry and load cases; equations given inline |
| **[EST]** | Engineering estimate — a judgement, not a measurement |
| **[DR]** | Derived from a secondary source that itself cites a primary one |
| **[UNV]** | Unverified — flagged as needing test or vendor confirmation |

**Two exchange rates are used throughout, both taken from `materials_pack.md` §6.8 and not re-derived:**

- **Mass → endurance: 1.5 h per kilogram** (at fixed 250 kg MTOW, added structure displaces fuel) [2][CALC]
- **Drag → endurance: 1.9 h per 0.001 of C_D0** (from the pack's own 0.020 → 0.022 = −3.8 h sensitivity) [2][CALC]

**Where this pack corrects `materials_pack.md`, it says so and shows the arithmetic.** There are three such corrections, in §2.2, §2.3 and §6.1.

**One geometry interpretation is load-bearing and is stated up front.** The task defines each boom as carrying one inverted-V panel, span 0.918 m, dihedral −42°, and the sponsor's item I contrasts the present arrangement (each boom "reacting the panel load in boom torsion individually") with one that "closes a structural loop between the booms". Those two statements are only consistent if **the panels run outboard-and-down from the boom aft ends, with nothing structural between the booms**: root at y = ±0.6206, tip at y = ±1.3028, z = −0.614 m. That is the geometry used here. §8.4 gives the numbers for the alternative (panels inboard-and-down, meeting on the centreline), which changes several conclusions and is flagged as an open question. [EST — inferred, not stated in `argus7_v1.yaml`, whose `tail.dihedral_deg` is itself tagged `assumption`.]

---

## 1. Answer first

**The sponsor is right about the resin, right about galvanic corrosion, right about UD-for-bending, and right that a tube needs woven plies as well. The sponsor is wrong about the aluminium, wrong about the wrap counts, wrong about which orientation the woven plies go in, and wrong about the tail attachment.**

| Sponsor's point | Verdict | The number |
|---|---|---|
| Low-viscosity laminating epoxy, not polyurethane | **Right, and for the stated reasons** | But West 105/205 specifically is a 975 cP marine coating system with a 2.81 GPa modulus [14][DS] against 3.0–3.9 GPa for a structural laminating/infusion epoxy [15][DS]. And **205 is the *fast* hardener** — wrong for a 3.6 m tube. Use a slow structural laminating system |
| Carbon-on-aluminium is a severe galvanic cell; interpose glass | **Right, and it is a real failure mode** | Aerospace practice is exactly this: "carbon fibres must be isolated from aluminium or steel using a barrier (liquid shim, glass ply)" [11][DS]. But **one 80–120 gsm ply is the documented minimum, not a comfortable margin** — the cited flight-hardware practice used *two to three* plies [DR]. See §11.2 |
| 200 gsm ply ≈ 0.25–0.30 mm cured under vacuum | **Right for a mediocre bag, pessimistic for a good one** | 0.25–0.30 mm corresponds to **Vf 0.37–0.44**. A properly bagged wet layup reaches Vf 0.50 → **0.222 mm**, and 0.55 → 0.202 mm [CALC][12][M] |
| UD at 0° between woven outer layers for bending | **Right, decisively** | 6 UD plies + 2 woven give E_x = 91.2 GPa against 59.0 GPa for the same thickness in all-woven — **+55% bending stiffness for the same mass** [CALC] |
| Woven "gives shear resistance" | **Wrong as usually built** | A woven wrapped warp-along-the-tube is a 0/90 laminate with **G_xy = 3.08 GPa**. Bias-wrapped at ±45 the *same cloth* gives **28.6 GPa — 9.3×** [CALC]. The torsional half of the sponsor's argument only exists if the weave is laid at 45° |
| Wrap count 3–4 / 6–8 / 10+ layers | **Wrong — the whole ladder undershoots** | Even **12 layers** on a 90 × 1.5 mm aluminium liner reaches only **90% of the required EI**, at **17.4 kg** for two booms [CALC]. See §4.1 |
| Aluminium tube stays in as a core | **Wrong, and it is the single most expensive decision in the proposal** | The liner alone is **5.5–16.1 kg = 8.3–24.2 hours of endurance**. At equal mass and equal radius, 1.5 mm of aluminium delivers **28.1 kN·m²** of EI where carbon delivers **69.5 kN·m² — 2.47×** [CALC]. See §3 |
| Vacuum bag at 25–29 inHg | **Right, and shrink tape is a genuine alternative for a tube** | Shrink tape is not merely a convenience: it delivers **0.4–1.2 MPa** of consolidation against the **0.1 MPa** ceiling of any vacuum process [13][M][9][DR]. For a 3.6 m tube it is the *better* method, not the fallback |
| Tail attached by two screws and a connector (revised scope) | **Wrong** | Two M6 at 60 mm centres carrying the 330 N·m panel root moment gives **306 MPa of bearing** against a **165 ± 28 MPa design bearing allowable** [19][DR] — a negative margin *before* fatigue. A 50 mm spigot in a 150 mm socket gives **1.76 MPa** [CALC]. See §7 |

**And the propwash premise is geometrically wrong, which is good news.** The propeller tip radius is 0.4065 m; the boom inner surface is at y = 0.5756 m. **The booms clear the prop tip by 169 mm (0.208 D) and clear the contracted slipstream by 183–209 mm at every power setting** [CALC]. The booms are not in the wash. They sit in its acoustic near field, where the differential pressure across a 110 mm cylinder at 70 Hz is ~0.14 × the local SPL — of order 10–30 Pa, not the ~300–560 Pa that a body inside the wake would see [CALC]. That 20–40× difference in excitation is the whole fatigue argument, and it is the strongest reason to keep both the booms *and* the tail panels outboard of the disc (§8.4).

**The headline numbers.**

| | 2-boom mass | Endurance vs the recommendation |
|---|---|---|
| Sponsor's build, sized to actually meet the stiffness requirement (Al 90 × 1.5 + 2.56 mm carbon) | **15.42 kg** (16.02 with fittings) | **−9.4 h (−0.39 d)** |
| Sponsor's build at the sponsor's own "10+ layer heavy duty" wrap count | 18.45 kg on a real 2 mm stock liner, **and 10% short of the required EI** | −14.0 h *and it still does not meet the requirement* |
| Current 90 mm spec, re-sized to the requirement | 10.06 kg (11.72 with fittings) | −3.0 h |
| **Recommended: COTS roll-wrapped 110 mm × 2.0 mm, no liner** | **7.54 kg** (9.20 with fittings) | **datum** |
| Same, hand-laid one-piece over a removable mandrel at Vf 0.50 | 6.61 kg (7.83 with fittings, no splice) | +2.1 h, at ~83 h of extra builder time |
| Same, hand-laid at a realistic bad-day Vf 0.40 | 7.94 kg (9.16 with fittings) | +0.1 h |

[CALC] **The aluminium liner and the inherited 90 mm diameter, together, are worth 9–14 hours — between a third and six-tenths of a day — of endurance.**

---

## 2. What the boom actually has to do

### 2.1 Geometry, restated from the source files

| | Value | Source |
|---|---|---|
| Boom length | 3.6456 m, x = 0.598 → 4.2436 | task / `derive_booms` |
| Boom station | y = ±0.6206 m | `argus7_v1.yaml` (13.4% semi-span) |
| Boom diameter | 90 mm, tagged **`assumption`** | `argus7_v1.yaml` provenance block [3] |
| Wing chord at the boom station | 537.9 mm (LE x = 0.7588, TE x = 1.2968) | [CALC] |
| Let-in | 19.5 mm burial = 21.7% of diameter; **111° wrapped arc**, 87.2 mm of arc length | [CALC] |
| Tail quarter chord | x = 4.0936 | task |
| Panel | S = 0.2808 m² each, span 0.918 m, taper 0.55, AR 3.0 | task |
| Panel mean/root/tip chord | 305.9 / 394.7 / 217.1 mm | [CALC] |
| Panel spanwise centre of pressure | **ȳ = 0.4146 m** from the boom axis | [CALC], trapezoid centroid (b/3)(1+2λ)/(1+λ) |
| Panel lift-curve slope | a_t = 3.563 /rad (a₀ = 5.73, AR 3) | [CALC] |
| S_h,eff check | 2 × 0.2808 × cos²42° = **0.3102 m²** ✓ matches the stated 0.31 | [CALC] |

**The effective cantilever length is 3.05 m, not 3.4 m.** Modelling the boom as a beam on two supports (wing front spar at 25% chord, rear spar at 70% chord, base a = 0.242 m) with a 2.958 m overhang to the tail quarter chord:

- δ_tip = P·L³/(3EI) + P·L²·a/(3EI) → **L_eff = 3.037 m** for deflection
- θ_tip = P·L²/(2EI) + P·L·a/(3EI) → **L_eff = 3.038 m** for slope
- Joint rotation contributes only **7.6%** of tip deflection and **5.2%** of tip slope

[CALC] **L_eff = 3.05 m** is used throughout. `materials_pack.md` used 3.4 m, which is conservative by 40% on moment. The short 0.242 m support base turns out *not* to dominate — a useful negative result, because it means lengthening the let-in buys very little stiffness (§7.2 shows it matters for a different reason).

### 2.2 Correction 1 — `materials_pack.md` understates the tail load by 1.81×

`materials_pack.md` §4.2 computes the tail load as "S_h = 0.31 m², C_N = 1.0 at q_D = 1,890 Pa → limit tail load 586 N, 440 N per boom ultimate" [2].

**0.31 m² is the *effective horizontal* area — the projected area already de-rated by cos²Γ. The aerodynamic load acts on the actual panel area, 0.2808 m² per panel, 0.5616 m² total.** The two conventions differ by exactly 1/cos²42° = **1.812**.

| Case | Per panel, limit | Total, limit |
|---|---|---|
| C_N = 1.0 at V_D = 200 km/h EAS (q_D = 1,890 Pa) | **530.8 N** | 1,062 N |
| C_N = 1.0 at V_A = 177.7 km/h EAS (q_A = 1,493 Pa) | 419.2 N | 838 N |
| Sharp-edged gust at V_C = 150 km/h EAS, U_de = 15.24 m/s, K_g = 0.75, (1−dε/dα) = 0.855 | 249.7 N | 499 N |
| **`materials_pack.md`'s figure** | 293.0 N | 586 N |

[CALC]. V_S = 25.33 m/s EAS at MTOW with C_Lmax 1.6; V_A = V_S√3.8 = 49.37 m/s; V_D = 55.56 m/s EAS is carried over from `materials_pack.md` and is **[EST]** — the report does not state a V_D (§15, open question 1).

**Design case adopted: C_N = 1.0 at V_D → 530.8 N per panel limit, 796 N ultimate.** This is deliberately the conservative envelope. It costs nothing, because §2.4 shows the boom is stiffness-critical by a factor of 3–4 in strength, so load conservatism does not buy mass.

Resolved at the boom (panel normal **n** = (0, sin Γ, cos Γ), force applied at ȳ = 0.4146 m):

| Component, ultimate, per boom | Value |
|---|---|
| Vertical (N cos 42°) | **592 N** |
| Lateral, outboard (N sin 42°) | **533 N** |
| Torque about the boom axis (N · ȳ) | **330 N·m** |
| Tail mass inertia at n_ult = 5.7 (1.6 kg) | 89 N |
| **Total vertical at the tail** | **681 N** |

[CALC] The torque is **2.2× the 150 N·m in `materials_pack.md` §4.2**, for the same reason — the area convention, plus a 0.4146 m arm rather than the 0.33 m assumed there.

### 2.3 Correction 2 — the torque does not cancel, and neither does the side load

For a V-tail on a single fuselage the two panels' torques about the fuselage axis cancel in the symmetric case. **On twin booms they do not.** Each boom individually reacts N·ȳ = 330 N·m ultimate, and the two booms twist in opposite senses. Likewise the two panels' lateral components both point outboard; there is nothing between the boom aft ends to react them, so **each boom carries 533 N of outboard shear at 3.05 m of arm = 1,626 N·m of lateral bending** all the way forward into the wing let-in joint.

Root moments, ultimate, per boom (including 5.7 g boom self-weight):

- Vertical: 681 × 3.05 + w·L²/2 = **2,334 N·m**
- Lateral: **1,626 N·m**
- Resultant: **2,845 N·m** — the lateral component adds **22%** to the root bending

[CALC] `materials_pack.md` §4.2 tabulates only "per-boom ultimate root bending 1,494 N·m". The corrected figure is **1.9× that**. It still does not make the boom strength-critical (§2.4) — but it makes the *wing let-in joint* a much more interesting problem (§7.2).

### 2.4 The boom is stiffness-critical — confirmed, with the corrected loads

At the corrected 2,845 N·m resultant, on a 110 mm × 2.0 mm roll-wrapped tube (I = 9.90×10⁻⁷ m⁴):

σ = M·r/I = 2,845 × 0.055 / 9.90×10⁻⁷ = **158 MPa** against a 620 MPa tensile allowable [4][DS] → **margin 3.9×**

[CALC] Across every candidate in §4 the margin runs **2.7× to 4.3×**. `materials_pack.md`'s finding stands, and it stands against loads 1.9× larger than the ones it used. **E/ρ, not σ/ρ, is the figure of merit. Nothing in this pack is decided by strength.**

What *is* decided by: stiffness (§4), torsional frequency (§5, §6), and joint durability (§7).

### 2.5 The stiffness criterion, stated and justified

Deflection is the wrong criterion. **Rotation is the right one**, because a cantilever's tip *slope* is what changes tail incidence, and the feedback is positive: tail load up → boom bends up → tail leading edge up → more tail load.

Four candidate criteria, evaluated:

| Criterion | Required EI | Binding? |
|---|---|---|
| Divergence margin V_div ≥ 2.0 V_D | 19.4 kN·m² | No |
| Aeroelastic tail-load amplification at V_D ≤ 10% | 53.6 kN·m² | No |
| Ultimate strength, MS ≥ 0 on 620 MPa | ~25 kN·m² | No |
| **Tail rotation ≤ 1.5° at limit load** | **80.7 kN·m²** | **Yes** |

**Why 1.5°.** At limit load the panel operates at C_N = 0.667, i.e. an incidence of 0.667/3.563 = **10.7°**. A NACA 0010 panel at AR 3 and Re ≈ 0.5–0.9 M stalls at roughly 14–16° three-dimensionally [EST]. The reserve is therefore 3.3–5.3°. A boom rotation of 1.5° consumes **28–45% of the tail's remaining incidence reserve** at the moment the tail is working hardest; 2.9° (which is what a 90 × 1.6 mm tube gives) consumes 55–88% and is not defensible. Tail stall at limit load is loss of pitch control.

At EI = 80.7 kN·m² the same criterion delivers, free: **V_div/V_D = 4.08**, and a tail-load amplification at V_D of **1.064**.

| Rotation limit | Required EI |
|---|---|
| 1.0° | 121.0 kN·m² |
| **1.5° (adopted)** | **80.7 kN·m²** |
| 2.0° | 60.5 kN·m² |
| 3.0° | 40.3 kN·m² |

[CALC] For reference, `materials_pack.md`'s recommended 90 × 2.5 mm tube (EI = 62.3 kN·m²) sits at **1.94°** — i.e. the pack implicitly adopted a 2° criterion. This pack tightens it to 1.5° and shows in §9 that the tightening is free if the diameter is opened up.

---

## 3. Question A — does the aluminium tube stay in?

### 3.1 The mass, and what it costs

A 90 mm OD aluminium tube, two booms, 3.6456 m each:

| Wall | Mass, 2 booms | Endurance |
|---|---|---|
| 1.0 mm | 5.50 kg | **−8.3 h** |
| 1.2 mm | 6.59 kg | **−9.9 h** |
| 1.5 mm | 8.21 kg | **−12.3 h** |
| **2.0 mm (the common stock wall)** | **10.88 kg** | **−16.3 h (−0.68 d)** |
| 3.0 mm | 16.14 kg | −24.2 h |

[CALC] at ρ = 2,700 kg/m³ and 1.5 h/kg [2].

Note the supply reality: **90 mm OD aluminium round tube is a stock item at 2 mm, 3 mm and 5 mm wall; 1.0–1.5 mm is not a standard extrusion in that diameter** [21][DS][UNV for the thin walls]. The sponsor's "thin 4 m aluminium tube" is realistically a 90 × 2 mm, i.e. **10.88 kg and 16.3 hours** before a single gram of carbon goes on.

### 3.2 The efficiency argument, at equal mass

For a thin-walled tube, both EI and mass are proportional to wall thickness at the same radius. So the figure of merit is **E/ρ, evaluated at the same radius** — exactly `materials_pack.md`'s finding, applied to the wall itself:

| Material at 90 mm mean diameter | E (GPa) | ρ (g/cm³) | E/ρ |
|---|---|---|---|
| 6061-T6 aluminium | 68.9 | 2.70 | **25.5** |
| Woven 0/90 carbon, wet layup Vf 0.50 | 59.0 | 1.50 | 39.4 |
| Roll-wrapped COTS tube wall | 94.7 | 1.523 | **62.2** |
| 6 UD + 2 woven ±45, wet layup Vf 0.50 | 91.2 | 1.50 | **60.8** |

Stated as the builder will experience it: **1.5 mm of aluminium (1.126 kg/m) buys 28.1 kN·m² of EI. The identical 1.126 kg/m spent on 2.66 mm of wet-layup carbon at the same radius buys 69.5 kN·m² — 2.47×.** At 2.0 mm the comparison is 36.9 vs 89.6 kN·m², the same ratio. [CALC]

There is no configuration in which the aluminium is the efficient way to carry bending in this tube.

### 3.3 The three options, sized to the same requirement

All sized to EI = 80.7 kN·m² (§2.5), 30% ±45 content, wet layup at Vf 0.50:

| Option | Carbon wall | Plies | 2-boom mass | Δ endurance |
|---|---|---|---|---|
| **(i)** Al 90 × 1.5 stays as structural liner | 2.56 mm | 11.5 | **15.42 kg** | **−12.5 h** |
| **(i)** Al 90 × 1.0 stays | 2.96 mm | 13.3 | 13.98 kg | −10.3 h |
| **(ii)** Al used as a *removable mandrel*, hollow CFRP 90 | 3.76 mm | 16.9 | 11.15 kg | −6.1 h |
| **(ii)** Al used as a removable mandrel, hollow CFRP **110** | 1.91 mm | 8.6 | **7.11 kg** | **datum** |
| **(iii)** Sacrificial / collapsible mandrel, hollow CFRP 110 | 1.91 mm | 8.6 | 7.11 kg | datum (−0.79 h drag) |

[CALC] Options (ii) and (iii) are identical structurally; they differ only in how the mandrel comes out.

### 3.4 What the liner genuinely buys, and what that is worth

Three real benefits, honestly valued:

1. **Crush and dent resistance.** A 90 × 1.5 mm aluminium liner will survive being clamped in a workbench vice; a 1.7 mm carbon tube will not. **But this is a local problem with a local fix**: bonded internal bulkheads and an external ±45 over-wrap at the three places that matter (the two let-in ends and the tail joint). Estimated **0.20 kg per boom** [EST], against 8.21 kg for the liner. **The liner is a 40× over-solution to a local problem.**
2. **It simplifies the wing let-in joint.** True, but only marginally: the let-in reacts 2,334 N·m over 538 mm as a 4,338 N couple, which even in a bonded 111° saddle is **0.185 MPa** of bond shear [CALC] — trivial against EA 9394's 28.9 MPa [6][DS]. What the joint actually needs is hoop restraint against the *lateral* couple (§7.2), which a metal liner does not provide either. **The liner does not solve the joint's real problem.**
3. **It is a free, straight, round, 4 m mandrel that you do not have to make.** This is the strongest argument in the proposal and it is a good one — but it is an argument for using the aluminium as a **mandrel**, not for leaving it in.

**Galvanic corrosion is a fourth, negative consideration that the sponsor identified correctly but under-weighted.** A permanent carbon/aluminium couple sealed inside a closed tube for a 2,000-hour airframe life is an inspection-impossible, repair-impossible interface. If a single glass ply is locally bridged by a stray carbon tow — which is exactly what happens at a wrap seam — the resulting cell is buried where nobody can see it. **Removing the aluminium removes the failure mode entirely.** That is worth more than the small probability-weighted mass it saves.

### 3.5 How to get a 3.65 m mandrel out

The extraction problem is real but solved industrially, and the mechanism is favourable:

- **Differential thermal contraction.** Aluminium's CTE is 23.6 µm/m·K; a UD-dominated carbon tube's hoop CTE is ~10–15 µm/m·K [EST]. Cooling from a 60 °C post-cure to 20 °C opens a diametral clearance of (23.6 − 12) × 10⁻⁶ × 40 × 90 mm ≈ **0.042 mm**. Small, but in the right direction.
- **Industrial practice runs it the other way and it works better:** roll-wrap production extracts the mandrel "while the tube is still slightly warm — typically 40–50 °C — when the differential thermal contraction between mandrel and composite provides the maximum extraction force reduction" [10][DR]. Chilling the mandrel (dry ice down the bore) while the tube is warm is the solo-builder version.
- **Taper.** Production mandrels are tapered ~0.1–0.2 mm/m. A parallel aluminium tube is not. **Mitigation: 2 layers of 25 µm PTFE film or FEP release film wrapped over the mandrel, spiral-wound with a 50% overlap and left with a tail to pull.** The film both releases and, when pulled, breaks the seal along the whole length.
- **Fallback that always works: cut the mandrel out.** Sacrifice the aluminium tube; slit it lengthwise from the ends with a long-reach cutter, or simply accept a €60–120 mandrel as consumable per boom. At €120/boom this is cheaper than one hour of a contractor's time.

### 3.6 Recommendation on question A

**Use the aluminium tube as a mandrel with release film, and remove it. Do not leave it in.**

- **Cost of leaving it in:** 8.21 kg (at 1.5 mm) to 10.88 kg (at the real 2 mm stock wall) = **12.3 to 16.3 hours of endurance**, plus a permanently buried galvanic interface, plus more carbon on top than the hollow tube needs because the aluminium is stiffness-inefficient.
- **Cost of taking it out:** roughly 2–4 hours of extraction work per boom, a €60–120 mandrel that may be consumed, and 0.4 kg of local internal reinforcement across both booms.
- **And if it will not come out:** you have lost the mandrel, not the boom. Slit it and pull it in pieces.

**The exchange rate is 30 hours of endurance per hour of extraction work.** [CALC]

---

## 4. Question B — wall thickness from the load case

### 4.1 What the sponsor's wrap counts actually deliver

On a 90 × 1.5 mm aluminium liner, using the sponsor's own 0.275 mm cured ply thickness and woven cloth wrapped 0/90 (the conventional way):

| Sponsor's band | Carbon wall | EI (kN·m²) | % of the 80.7 required | GJ | 2 booms | Tail rotation at limit |
|---|---|---|---|---|---|---|
| bare liner, no carbon | — | 28.1 | 35% | 21.2 | 8.21 kg | 4.30° |
| **3 layers** "light duty" | 0.82 mm | 40.2 | **50%** | 21.4 | 10.58 kg | 3.01° |
| 4 layers | 1.10 mm | 44.0 | 55% | 21.5 | 11.37 kg | 2.75° |
| **6 layers** "general structural" | 1.65 mm | 51.5 | **64%** | 21.6 | 12.91 kg | 2.35° |
| 8 layers | 2.20 mm | 58.7 | 73% | 21.8 | 14.44 kg | 2.06° |
| **10 layers** "heavy duty" | 2.75 mm | 65.6 | **81%** | 21.9 | 15.94 kg | 1.85° |
| 12 layers | 3.30 mm | 72.2 | 90% | 22.0 | 17.43 kg | 1.68° |

[CALC]

**Three things fall out of this table and all three are decisive:**

1. **The ladder never arrives.** Twelve layers — 50% more than the top of the sponsor's "heavy duty" band — still reaches only 90% of the required EI, at **17.4 kg for two booms**. The recommended hollow 110 mm tube reaches 100% at **7.5 kg**. The proposal is not slightly heavy; it is **2.3× the mass and still short**.
2. **The sponsor's intuition about "still noticeably flexible over 4 m" is correct and well-calibrated.** 3 layers gives 3.0° of tail rotation. The intuition is right; only the conclusion drawn from it ("use more layers") is wrong. The right conclusion is "use a bigger tube".
3. **GJ barely moves — 21.2 → 22.0 kN·m² across the whole ladder.** Because the woven is at 0/90 (G = 3.08 GPa), *all* of the torsional stiffness is coming from the aluminium liner. Adding twelve plies of carbon adds **4%** to torsional stiffness. This is the single clearest demonstration that the weave orientation, not the weave count, is what matters (§5).

### 4.2 The layup that does meet the requirement

Classical lamination theory, ply properties from micromechanics at the stated Vf (E_f1 = 230 GPa, E_m = 3.2 GPa, Halpin-Tsai transverse and shear, 5% crimp knockdown on woven warp/weft):

| Stack (200 gsm plies) | t at Vf 0.50 | E_x (GPa) | G_xy (GPa) | E/ρ | %0° |
|---|---|---|---|---|---|
| 6 woven, 0/90 | 1.33 mm | 59.0 | **3.08** | 39.4 | 50 |
| 6 woven, ±45 | 1.33 mm | 11.2 | **28.60** | 7.5 | 0 |
| 2 woven±45 + 4 UD0 + 2 woven±45 *(sponsor's stack, charitable reading)* | 1.78 mm | 64.7 | 15.84 | 43.2 | 50 |
| 2 woven0/90 + 4 UD0 + 2 woven0/90 *(literal reading)* | 1.78 mm | 88.0 | **3.08** | — | — |
| **1 woven±45 + 6 UD0 + 1 woven±45** | **1.78 mm** | **91.2** | 9.46 | **60.8** | 75 |
| 2 woven±45 + 6 UD0 + 2 woven±45 | 2.22 mm | 75.4 | 13.29 | 50.2 | 60 |
| COTS roll-wrapped reference [4][DS] | — | 94.7 | 11.68 | 62.2 | ~60 |

[CALC] from [4][7]

**The recommended hand layup, if hand-laying:**

```
110 mm mandrel, inside → outside:
  1 × 200 gsm 3k twill, BIAS-WRAPPED at ±45        0.22 mm   torsion, inner surface
  6 × 200 gsm UD carbon at 0° (staggered seams)    1.33 mm   bending
  1 × 200 gsm 3k twill, BIAS-WRAPPED at ±45        0.22 mm   torsion, abrasion, outer surface
                                                   ────────
                                        8 plies    1.78 mm at Vf 0.50
```

- **EI = 80.7 kN·m²** ✓ (meets §2.5 exactly at Vf 0.50)
- GJ = 16.7 kN·m²
- σ_ult = 183 MPa on a 620 MPa allowable → **MS 3.4** ✓
- Shell buckling: σ_cr ≈ 0.3·√(E_x E_y)·t/R = **520 MPa** → MS 2.8 ✓
- **0.908 kg/m → 3.31 kg per boom, 6.62 kg for two**

**A result worth stating on its own, because it inverts the usual worry about wet layup:**

| Vf achieved | Cured wall | E_x | EI (= E·I) | 2-boom mass |
|---|---|---|---|---|
| 0.55 | 1.62 mm | 100.1 GPa | 81 kN·m² | 6.12 kg |
| **0.50** | 1.78 mm | 91.2 GPa | 81 kN·m² | 6.61 kg |
| 0.45 | 1.98 mm | 82.3 GPa | 81 kN·m² | 7.20 kg |
| 0.40 | 2.22 mm | 73.5 GPa | 81 kN·m² | 7.94 kg |

[CALC] **For a fixed ply count, EI is essentially independent of fibre volume fraction** — E falls and t rises in near-exact compensation (E·t = 162 ± 1 kN/m across the whole range). **A resin-rich layup does not cost you stiffness. It costs you mass, at 1.5 h/kg.** A bad bag that lands at Vf 0.40 instead of 0.50 costs **1.33 kg = 2.0 hours** and nothing else. That is a much more forgiving failure mode than the folklore suggests, and it means the layup schedule should be written in **plies, not millimetres**.

### 4.3 Strength check, as the secondary criterion it is

At the recommended 110 × 1.78 mm hand layup, ultimate resultant root moment 2,845 N·m:

| Check | Value | Allowable | MS |
|---|---|---|---|
| Axial bending stress | 183 MPa | 620 MPa (tension) [4][DS] | **3.4** |
| Torsional shear, T = 330 N·m | 4.9 MPa | ~70 MPa (±45 laminate) [EST] | **14** |
| Local shell buckling in bending | 183 MPa | 520 MPa | 2.8 |
| Brazier ovalisation | — | not critical at t/R = 0.032 | — |

[CALC] **Nothing is close.** This is the boom's defining characteristic and every decision in this pack respects it.

---

## 5. Question C — torsion, ±45 content, and where "only half the fibres run lengthwise" gets decided

### 5.1 The sponsor's point 4 is half right, and the wrong half is the important one

> "woven twill/plain gives hoop strength and shear resistance but only half the fibres run lengthwise"

**Hoop strength: right.** A 0/90 woven contributes E_y ≈ 59 GPa in hoop, which is what resists crushing at clamps and local ovalisation.

**Shear resistance: wrong as built.** A woven cloth wrapped with its warp along the tube axis produces a **0/90 laminate**, whose in-plane shear modulus is just the ply's G₁₂ = **3.08 GPa**. That is *lower than epoxy-dominated*; it is 8× worse than aluminium (25.9 GPa) and 3.8× worse than the COTS roll-wrapped tube (11.68 GPa) [4][DS]. **The same cloth bias-wrapped at ±45 gives 28.6 GPa — a factor of 9.3, for zero mass change.**

**This is the single cheapest correction in the pack.** Cut the woven on the bias (or spiral-wrap it at 45°). Nothing else changes.

### 5.2 How much ±45 the boom actually needs

The torsional requirement is not strength (§4.3 shows a margin of 14×). It is **frequency**. The boom's first torsional mode is:

f_t1 = (1/2π)·√( (GJ/L) / (J_tail + J_boom·L/3) )

with **J_tail = m_panel·b²/3 = 0.365 kg·m²** about the boom axis — a big polar inertia, because a 1.3 kg panel hangs 0.918 m off the axis. At D = 110 mm with the wall always re-sized to hold EI = 80.7 kN·m²:

| Stack | %±45 | wall | E_x | G_xy | GJ (kN·m²) | **f_t1** | 2 booms |
|---|---|---|---|---|---|---|---|
| 6 UD 0° only | 0% | 1.37 mm | 116.6 | 3.08 | 4.3 | **9.8 Hz** | 5.13 kg |
| **1w±45 + 6UD + 1w±45** | **25%** | 1.78 mm | 91.2 | 9.46 | 16.7 | **19.4 Hz** | 6.61 kg |
| 2w±45 + 6UD + 2w±45 | 40% | 2.17 mm | 75.4 | 13.29 | 23.5 | 23.0 Hz | 8.05 kg |
| 4w±45 + 6UD + 4w±45 | 57% | 2.93 mm | 57.1 | 17.66 | 49.9 | 33.3 Hz | 10.77 kg |
| 6w±45 + 6UD + 6w±45 | 67% | 3.63 mm | 46.9 | 20.09 | 69.1 | 39.2 Hz | 13.28 kg |
| **COTS roll-wrapped** | ~30% | 1.71 mm | 94.7 | 11.68 | 19.9 | **21.1 Hz** | **6.45 kg** |

[CALC]

**The trade is brutally non-linear and this is the number that decides it:** going from 25% to 57% ±45 raises the torsional frequency by 1.7× and costs **4.16 kg = 6.2 hours of endurance**. Buying torsional frequency with ±45 plies is the most expensive lever on the boom, because every ±45 ply displaces a 0° ply and forces the wall thicker to hold EI.

**Two cheaper levers exist and both should be used before adding a single ±45 ply:**

- **Halve the tail panel's polar inertia** → f_t1 × 1.41, free. The panel's inertia is m·b²/3; moving mass inboard (root-mounted servo instead of mid-span, lighter tip, no tip weight) attacks b² directly. A 0.65 kg panel instead of 1.3 kg gives the same 1.41× as adding 4 kg of ±45.
- **Close the tail loop** → f_t1 × 1.30 to 2.41 for 0.34–0.55 kg (§8).

**Recommendation: 25–30% ±45, i.e. one bias-wrapped woven ply inside and one outside a 6-ply UD core.** That is what the COTS roll-wrapped tube already is, and it is not a coincidence — it is where the trade lands.

### 5.3 Divergence and classical flutter

**Divergence** at the recommended stiffness: q_div = 1/(S_h,eff,boom · a_t · K_θ) with K_θ = L²/(2EI) = 5.66×10⁻⁵ rad/N →

q_div = 31,500 Pa → **V_div = 4.08 V_D = 816 km/h EAS**. [CALC] Not a constraint.

**Boom torsion does not feed pitch.** A rotation φ about the boom's longitudinal axis leaves the panel's chord line parallel to the flow; the panel's angle of attack is unchanged (Ω·**s** = 0, since the panel span vector has no x-component). Boom torsion changes the panel's *dihedral*, which is a lateral-directional effect, not a pitch one. **So the classic wing bending–torsion flutter mechanism is not the one to worry about here.** The two mechanisms that are:

1. **Symmetric boom bending + tail pitch.** The elastic axis is the boom axis. If the boom axis passes through the panel's quarter-chord line, the aerodynamic pitching moment about the elastic axis is ~zero and the only coupling is inertial. **Design rule: put the boom axis at or slightly ahead of the panel's 25% chord line, and mass-balance the panel so its CG is at or ahead of the boom axis.** With those two conditions the binary system is flutter-free to first order, at zero mass cost if done at the design stage. [DR — standard practice; the mass-balance rule is the same one that governs control surfaces]
2. **Ruddervator rotation mode.** For a UAV this is the realistic flutter risk, because the "hinge stiffness" is a servo gearbox with backlash. **Mass-balance the ruddervator about its hinge line, use a zero-backlash linkage, and keep the surface-rotation frequency above the boom's first torsion mode (19–21 Hz).** [DR]

Neither of these is a boom-layup question. They belong on the tail drawing, and §7 argues they are now *more* important because the tail has become a removable item.

---

## 6. Question G — boom frequencies versus blade-passage excitation

### 6.1 Correction 3 — the booms are not in the slipstream

| | Value |
|---|---|
| Propeller diameter, from `argus7_v1.yaml` | 0.813 m → tip radius **0.4065 m** |
| Boom axis | y = 0.6206 m |
| Boom inner surface (90 mm) | y = 0.5756 m |
| **Radial clearance, boom surface to prop tip** | **169 mm = 0.208 D** |
| Slipstream radius aft of the disc, loiter (T = 91 N, a = 0.078) | 0.393 m → boom clear by **183 mm** |
| Slipstream radius aft of the disc, full power SL (T = 442 N, a = 0.298) | 0.367 m → boom clear by **209 mm** |
| Tail panels (outboard-and-down): minimum radius from the thrust axis | **0.621 m** — entirely outside the disc |

[CALC] Slipstream contraction from R_w/R = √((1+a)/(1+2a)).

**The booms and the tail are outside the propeller slipstream at every power setting, and the slipstream contracts *away* from them as power increases.** The premise "the booms extend aft of the prop and sit in its slipstream, excited continuously" is geometrically incorrect. The excitation is real but it is **near-field acoustic, not wake impingement**, and the difference in amplitude is 20–40×:

| Location | Unsteady pressure at BPF |
|---|---|
| **Inside the slipstream**, blade-wake velocity defect ±10–20% at q_slip = 1,404 Pa | **281–562 Pa** [CALC] |
| **Outside at 0.21 D tip clearance**, near-field SPL 130–140 dB | 63–200 Pa SPL, but the acoustic wavelength at 70 Hz is 4.9 m against a 0.11 m cylinder, so the *differential* across the boom is (kD)·p = 0.14 p ≈ **9–28 Pa** [CALC][EST] |

0.208 D of tip clearance is also right at the conventional design floor — propeller-to-structure clearance guidance sits at **≥ 0.2 D** for exactly this reason [16][DR]. ARGUS-7 passes, with nothing to spare. **Any change that moves a boom, a tail panel or a cross-member inboard of r = 0.45 m converts a 20 Pa problem into a 400 Pa problem, and every conclusion in this section reverses.** That is the strongest single argument in this pack for keeping the tail panels outboard (§8.4).

### 6.2 The excitation comb is not a single frequency, and it is not currently determinable

| Source | At prop 2,100 rpm (the yaml value) | At the loiter rpm a fixed-pitch prop would actually turn |
|---|---|---|
| Prop 1P (shaft order) | 35.0 Hz | ~23 Hz |
| 2-blade BPF | **70.0 Hz** | ~47 Hz |
| 3-blade BPF | **105.0 Hz** | ~70 Hz |
| Engine firing (single-cyl 4-stroke, 4,830 rpm) | 40.25 Hz | ~27 Hz |
| Engine 1st order | 80.5 Hz | ~54 Hz |
| 2× BPF (2-blade) | 140 Hz | ~93 Hz |

**And the propulsion numbers do not close, which makes this worse.** A 0.813 m propeller at 2,100 rpm absorbing 17 kW at sea level requires a power coefficient of

C_P = P/(ρ n³ D⁵) = 17,000/(1.225 × 35³ × 0.813⁵) = **0.911**

[CALC] Realistic maximum C_P for a two-blade propeller at these advance ratios is 0.15–0.25; even a heavily loaded four-blade tops out near 0.4. **The report's prop diameter, reduction ratio, rpm and power are mutually inconsistent by roughly 4× in C_P.** Either the reduction ratio is nearer 1.5:1 (giving ~3,200 prop rpm and a 107 Hz two-blade BPF), or the propeller is larger, or 17 kW is never delivered at 2,100 rpm. Until that is resolved, **the blade-passage frequency is uncertain by roughly ±50%, from about 47 Hz to about 107 Hz.** Logged as open question 2.

### 6.3 The mode map

Euler–Bernoulli beam FE of the actual boom (x = 0.598 → 4.2436, pinned at the wing front and rear spar stations, 1.6 kg tail mass and 0.174 kg·m² pitch inertia at x = 4.0936), plus a torsional rod model fixed at the mid-let-in station with the 0.365 kg·m² panel inertia at the tail:

| Build | f_b1 | f_b2 | f_b3 | f_t1 |
|---|---|---|---|---|
| Al 90 × 1.5 liner + 8 plies carbon | 6.8 | **48.0** | 124.0 | 27.5 |
| Al 90 × 2.0 liner + 8 plies carbon | 7.0 | **47.9** | 125.3 | 29.7 |
| COTS 90 × 1.6 | 7.1 | **57.4** | 139.9 | 15.1 |
| COTS 90 × 2.5 (`materials_pack.md`'s pick) | 8.1 | **61.5** | 153.2 | 18.6 |
| COTS 100 × 2.0 | 8.8 | **67.6** | 167.3 | 19.7 |
| **COTS 110 × 2.0 (recommended)** | **10.0** | **75.8** | **188.5** | **22.7** |
| COTS 120 × 1.6 | 10.5 | **81.2** | 200.5 | 23.3 |
| Hand-laid 110 × 1.78 (8 ply) | 9.5 | 74.0 | 182.4 | 19.4 |

[CALC] Higher modes: f_b4 ≈ 300 Hz, f_b5 ≈ 540 Hz; the lowest shell ovalling mode of a 110 × 2 mm carbon tube is **>400 Hz** [CALC], so no shell mode is in play.

**Two scaling laws govern the design space and both matter:**

- **f_bending ∝ D at constant EI.** For a thin tube, EI ∝ D³t and mass ∝ Dt, so at fixed EI the frequency scales linearly with diameter and is independent of wall thickness. Across D = 80 → 140 mm, f_b2 moves only **56 → 86 Hz**.
- **f_torsion is completely insensitive to diameter at constant EI**, because GJ tracks EI for a given laminate and the tail inertia is fixed: 18.5 Hz at every diameter in the sweep. Only the ±45 fraction and the tail's polar inertia move it.

### 6.4 The separation margin, the criterion, and the honest verdict

**Criterion adopted: ±20%.** This is the standard resonance-avoidance separation — "many major vibration problems can be avoided by making sure the excitation frequency does not fall within a 20 percent range around the natural frequencies" [17][DR], and it is the margin implicit in FAA AC 20-66B's treatment of propeller-induced vibration and the associated fatigue evaluation [16][DR].

Applying it to the 2,100 rpm comb gives keep-out bands of 29.8–46.3 Hz (prop 1P + engine firing), **59.5–92.6 Hz** (2-blade BPF + engine 1st order), 89.3–120.8 Hz (3-blade BPF) and 119–185 Hz (2×BPF + engine 2nd order). The clear windows below 200 Hz are **< 29.8 Hz**, **46.3–59.5 Hz** and, with a two-blade propeller only, **92.6–119 Hz**.

| Mode, recommended 110 × 2.0 build | Frequency | Verdict |
|---|---|---|
| **f_b1** | 10.0 Hz | **PASS** — 3.5× below the lowest comb line, and 5× above a realistic 2 Hz autopilot pitch bandwidth |
| **f_t1** | 22.7 Hz | **PASS at 2,100 rpm** (35% clear of 35 Hz and 44% clear of 40.25 Hz) — **FAILS at the loiter rpm**, where prop 1P is ~23 Hz. See below |
| **f_b2** | 75.8 Hz | **FAILS** — 8% above 70 Hz, 6% below 80.5 Hz. There is no escape by diameter: to reach the 92.6–119 Hz window needs D ≈ 137–176 mm |
| **f_b3** | 188.5 Hz | PASS — 17% above 161 Hz, marginal |

**So the frequencies cannot all be separated at any sensible diameter, and it is more honest to say so than to pretend a layup change fixes it.** What remains is to compute the consequence.

### 6.5 The consequence, computed

Forced-response of the FE model to a harmonic differential pressure applied over the 1.2 m of boom nearest the propeller plane, with a CFRP structural damping ratio ζ = 0.01–0.05 (Q = 10–50):

| Excitation | Static root stress | At resonance, Q = 10 | Q = 25 | Q = 50 |
|---|---|---|---|---|
| **20 Pa** (near field, computed §6.1) | 0.42 MPa | 4.2 MPa / 0.004% | 10.4 MPa / 0.011% | 20.9 MPa / 0.022% |
| 50 Pa | 1.04 MPa | 10.4 MPa / 0.011% | 26.1 MPa / 0.028% | 52.2 MPa / 0.055% |
| 200 Pa | 4.18 MPa | 41.8 MPa / 0.044% | 104 MPa / 0.110% | 209 MPa / **0.221%** |
| **400 Pa** (*if it were inside the slipstream*) | 8.35 MPa | 83.5 MPa / 0.088% | 209 MPa / **0.221%** | 418 MPa / **0.441%** |

[CALC] strain quoted as σ/E_x on the 94.7 GPa laminate.

**The allowable to compare against is the matrix fatigue-limit strain: ε_mf = 0.6% for epoxy resins, below which no damage progression occurs — this is the mechanism that gives CFRP its very-high-cycle behaviour, since matrix micro-cracking is the principal driver of CFRP fatigue failure** [18][M].

| | Peak vibratory strain | Margin to ε_mf = 0.6% |
|---|---|---|
| **As designed (booms outside the slipstream, Q = 25)** | **0.011%** | **55×** |
| Pessimistic (200 Pa, Q = 50) | 0.221% | 2.7× |
| **If a member is placed inside the slipstream at Q = 50** | **0.441%** | **1.4× — not acceptable** |

**Verdict on item G.** The boom's second bending mode will sit inside the blade-passage keep-out band and there is no affordable way to move it. **That is acceptable, and the reason it is acceptable is entirely geometric: the boom is not in the wash.** The vibratory strain is 0.011%, which is 55× below the threshold at which CFRP accumulates matrix damage at all, and 28.4 M or 504 M cycles at a strain that causes no damage per cycle is still no damage.

**The design action that follows is not a layup change. It is three prohibitions:**

1. **Nothing structural inside r = 0.45 m of the thrust axis aft of the prop plane.** This is now a configuration constraint, and it is the reason §8 recommends against a naïve cross-tie at z = 0.
2. **f_b1 must stay below 25 Hz and f_t1 must be resolved against the true loiter rpm once the propulsion set closes** (§6.2). f_t1 = 22.7 Hz against a possible ~23 Hz prop 1P at loiter is a **1% separation for 122 continuous hours** and it is the one genuine resonance risk in the mode map. The fixes, in cost order: reduce the panel's polar inertia (free, ×1.41), close the tail loop (0.4 kg, ×1.30–1.55), add ±45 (4 kg, ×1.7). **Do the first two.**
3. **Measure it.** A single tap test on the finished boom with the tail fitted, and a ground run with an accelerometer at the tail, settles the whole section in an afternoon. Everything above is a model.

---

## 7. Question H — fatigue of the layup and, more importantly, of the joints

### 7.1 The laminate is not the fatigue article; say so and move on

Three load spectra act on the boom:

| Spectrum | Cycles per 112.8 h mission | Peak strain |
|---|---|---|
| Blade-passage vibration (§6.5) | **28.4 M** (2-blade) / 42.6 M (3-blade) | 0.011% |
| Atmospheric turbulence / gust, 0.1–2 Hz | ~10⁵–10⁶ | ~0.03–0.08% [EST] |
| Manoeuvre and recovery | 10²–10³ | up to 0.19% at limit |

[CALC] Against ε_mf = 0.6% [18][M] and a 1-g steady strain of 0.019%, **the laminate has 3× margin at limit load and 55× at the vibratory level.** Carbon/epoxy at these strains is, for practical purposes, fatigue-immune — the same conclusion `materials_pack.md` §8.1 reached for the spar cap, reached here independently for the boom.

**The honest caveat: published CFRP S-N data essentially stops at 10⁷ cycles.** The 504 M-cycle 2,000-hour figure is an extrapolation, and the VHCF literature warns that CFRP shows "no traditional fatigue limit" and a step in the S-N curve in the HCF→VHCF transition [18][M]. The defence is not the extrapolation; it is the 55× strain margin.

### 7.2 The boom-to-wing joint — the one whose failure loses the aircraft

**Geometry.** A 19.5 mm burial of a 90 mm boom gives a contact half-angle of 55.5°, a **111° wrapped arc**, 87.2 mm of arc length and a 74.2 mm chord width, over the 538 mm wing chord at that station. [CALC]

**Vertical loads are trivial.** The 2,334 N·m ultimate vertical moment reacted over the 538 mm let-in is a 4,338 N couple; smeared over the bonded arc it is **0.185 MPa** of adhesive shear against EA 9394's 28.9 MPa [6][DS]. A margin of 156×.

**The lateral load is the problem, and it is the one `materials_pack.md` did not see because it did not have the side-force term (§2.3).** The 1,626 N·m lateral ultimate moment produces a **3,022 N** couple acting to prise the boom sideways out of a 111° open saddle. Over most of that arc the load has a component **normal to the bondline**. EA 9394's T-peel strength is **22 N per 25 mm** [6][DS] — 800× lower than its shear strength. `materials_pack.md` §7.1 states the governing rule for the whole aircraft: *design every bonded joint to work in shear or compression; never let a bondline see peel.* **A 111° saddle carrying a lateral couple violates that rule.**

**The fix, and it is cheap:**

- Two **full-circumference clamped collars**, one at each end of the let-in, each 60–80 mm long: a split aluminium or CFRP ring, bonded *and* through-bolted, that converts the lateral couple into hoop compression and shear rather than bond peel. ~0.15 kg per boom.
- **A ±45 over-wrap** of 3 plies of 200 gsm carbon (or aramid, which is tougher in this role) over the full 538 mm of let-in, taken around 360°. This is `materials_pack.md` §7.2's own prescription for tube-to-fitting joints — "over-wrap tube-to-fitting joints circumferentially to convert peel into hoop tension" [2] — applied to the joint that most needs it. ~0.12 kg per boom.
- **Internal bulkheads** at both ends of the let-in to stop the tube ovalising under the collar. 2 × 30 g of Rohacell-and-carbon disc per boom.
- **A glass ply** between the carbon boom and any aluminium collar (§11.2).

Total local reinforcement at the wing joint: **≈ 0.20 kg per boom**, 0.60 h of endurance for both booms — against a boom-loss failure mode.

**Fatigue verdict on the wing joint.** Bonded, in shear, at 0.185 MPa ultimate = 0.6% of static: adhesive fatigue thresholds sit near 20–30% of static shear [EST][DR], so the margin is ~40×. **The bonded path is fine. The bolted path through the collars must be preloaded and close-fit, not clearance-fit** (§7.3).

### 7.3 The boom-to-tail quick-release — two screws will not do

The sponsor's revised scope makes the tail a serviceable item: "two screws and a quick connector". The panel root reactions the joint must carry are **796 N of shear and 330 N·m of bending, ultimate** (220 N·m limit).

| Arrangement | Bolt shear | Bearing on the laminate | vs static ~600 MPa | vs **design allowable 165 ± 28 MPa** [19][DR] |
|---|---|---|---|---|
| **2 × M6 at 60 mm centres** | 5,500 N | **306 MPa** | MS 1.96 | **MS 0.54 — FAILS** |
| 2 × M6 at 120 mm centres | 2,750 N | 153 MPa | MS 3.93 | MS 1.08 — marginal |
| 4 × M6 in a 120 × 60 pattern | 1,375 N | 76 MPa | MS 7.85 | MS 2.17 |
| 2 × M8 at 150 mm centres, 4 mm laminate | 2,200 N | 69 MPa | MS 8.73 | MS 2.39 |
| **Spigot Ø40 × 120 mm engagement** | — | **3.44 MPa** | MS 175 | MS 48 |
| **Spigot Ø50 × 150 mm engagement** | — | **1.76 MPa** | MS 341 | MS 94 |
| Full 110 mm socket × 150 mm engagement | — | 0.80 MPa | MS 750 | MS 206 |

[CALC], peak spigot bearing from p = 6M/(d·ℓ²) for a linear bearing distribution.

**Two clearance-fit M6 screws at 60 mm centres are not a viable tail attachment**, before fatigue is considered. With fatigue considered they are worse: composite bolted joints fail by progressive **hole elongation and fretting**, a four-stage compressive damage accumulation (onset, growth, local fracture, structural fracture) in which preload is lost as the hole wears, which accelerates the wear [19][M]. There is no mechanism by which a clearance-fit shear bolt in a composite laminate survives 28 M cycles at 60–100 MPa of bearing without measurable elongation.

**Recommendation, in preference order:**

1. **Spigot-and-socket, with the screws taking only retention.** A Ø50 × 150 mm spigot bonded into the panel root, entering a socket bonded into the boom. The moment is reacted as **1.76 MPa** of distributed bearing over a large area; the two screws see only axial pull-out and a small torque, not the 5.5 kN couple. **This is standard removable-tailplane practice on gliders and it costs nothing extra to build.** Fit a single spring-plunger or a captive clamp bolt, plus one 3-pin connector for the ruddervator servo.
2. If the sponsor insists on a purely bolted joint: **4 × M8, close-fit (H8/h7) with bonded-in aluminium or titanium bushes**, spread over ≥ 150 × 80 mm, with a glass isolation ply under every bush (§11.2), at a controlled preload. This works but is heavier, fiddlier and slower to service than the spigot.
3. **Never** two screws.

**Relocating the quick-release, as the coordinator suggests.** The right answer is (i): **the release should be outboard of the fatigue-critical structure, but the fatigue-critical structure at this joint is the *panel root*, not the boom.** Placing the release at the panel root is correct — provided it is a spigot, not a bearing joint. Placing it further outboard (part-span) would put a joint in the middle of a lifting surface for no gain.

**If a bolted joint is used anyway, here is the life-limit regime**, and it should be written on the drawing:

- Inspect at **25 flight hours** after first fit, then every **50 flight hours**.
- Measure hole elongation with a pin gauge. **Replace the panel root fitting at 2% elongation** — 0.12 mm on a 6 mm hole, 0.16 mm on an 8 mm hole — which is the conventional bearing-failure criterion [19][DR].
- Re-torque at every inspection; a falling torque reading is the leading indicator and it precedes measurable elongation.
- **Log it as a life-limited item.** [EST for the intervals — they are engineering judgement anchored on the four-stage damage model in [19], not measured on this joint. Open question 6.]

### 7.4 The framing the sponsor should hear

**Making the tail sacrificial is a sound decision, and it does reduce risk — but it moves risk, it does not delete it.** A tail panel that departs in flight is a recoverable event only if the *boom* and the *joint* are undamaged. A quick-release joint that wears is a joint that transmits its wear into the boom's end fitting, and a boom failure is not recoverable. The correct expression of "sacrificial tail" is therefore:

> The **panel** is sacrificial. The **spigot, the socket, the boom end fitting and the boom** are permanent, and the joint must be designed so that all the wear happens in the removable half.

Practically: put the bushes, the threads and the wear surfaces **in the panel-root fitting**, which is replaced with the panel. The boom's socket should be a plain bonded CFRP or hard-anodised aluminium bore with nothing in it that can wear out.

---

## 8. Question I — does closing the tail loop help?

### 8.1 What "closing the loop" does, mechanically

With the panels outboard-and-down (§0), the boom aft ends are free. Adding a spanwise member between them (ℓ = 1.2412 m) does three distinct things, of very different value:

**(a) It reacts the lateral tail load panel-to-panel.** The two panels each push outboard with 533 N ultimate; a tie takes that in tension and deletes the 1,626 N·m of lateral bending from both booms and from the wing let-in joint (§7.2).

Root moment: **2,845 N·m open → 2,334 N·m closed = 17.9% lower.** [CALC]

Converted to life through S = S₀N^(−1/m):

| S-N exponent m | Applicable to | Life multiplier |
|---|---|---|
| 6 | bonded and bolted joints, matrix-dominated | **×3.3** |
| 8 | composite bolted joints | ×4.9 |
| 10 | mixed | ×7.2 |
| 14–20 | UD carbon in tension | ×16 – ×52 |

[CALC][EST for the exponents — CFRP S-N is conventionally fitted linear-log rather than as a power law, so these are indicative]

**(b) It adds a rotational restraint against boom torsion at the aft end**, in parallel with the boom's own GJ/L = 6,983 N·m/rad. For symmetric loading the two boom-end rotations are equal and opposite, so the tie contributes k = 2EI_tie/ℓ:

| Tie | k_tie | Boom's share of the torque | **f_t1** | Mass | Faired drag |
|---|---|---|---|---|---|
| 40 × 1.5 mm carbon tube | 4,882 N·m/rad | 59% | 21.1 → **27.5 Hz** (×1.30) | 0.34 kg (−0.5 h) | −1.9 h |
| **50 × 1.5 mm** | 9,755 | **42%** | → **32.7 Hz** (×1.55) | 0.43 kg (−0.6 h) | **−2.4 h** |
| 60 × 1.5 mm | 17,113 | 29% | → 39.2 Hz (×1.86) | 0.51 kg (−0.8 h) | −2.9 h |
| 80 × 1.2 mm | 33,447 | 17% | → 50.8 Hz (×2.41) | 0.55 kg (−0.8 h) | −3.9 h |

[CALC] Faired drag assumes a 3:1 streamline fairing at C_D = 0.08 on frontal area.

**(c) It raises the antisymmetric boom modes and stiffens the whole empennage in yaw** — qualitatively valuable, not quantified here.

### 8.2 What it costs, and the cost that kills the naïve version

- **Mass:** 0.34–0.55 kg for the member, plus two end joints at ~0.10 kg each = **0.54–0.75 kg → 0.8–1.1 h**.
- **Drag, faired:** **1.9–3.9 h**. This dominates.
- **Drag, unfaired round tube:** at C_D = 1.0 on frontal area, a bare 40 mm tube across 1.24 m is ΔC_D0 = 0.0127 → **−24.2 hours**. **A bare cross-tube is a mission-ending drag item. If a tie is fitted it must be faired, full stop.** [CALC]
- **Two more joints**, in a load path that is now primary, and both of them in the region where §6 wants nothing.
- **And the fatal one: a member at z = 0 spanning y = −0.62 to +0.62 passes straight through the propeller slipstream** (radius 0.37–0.39 m). §6.5 shows that puts it at 281–562 Pa of blade-passage excitation instead of ~20 Pa, and at Q = 50 that reaches 0.44% strain — within 1.4× of the matrix fatigue limit. **The cross-tie would become the fatigue article of the aircraft.**

### 8.3 Recommendation on question I

**Do not fit a bare cross-member at the tail. The physics says the loop is worth closing; the geometry says this is the wrong place to close it.**

The ledger for a 50 mm faired tie: **+3.3× to +7.2× joint life and f_t1 × 1.55 (which fixes the one genuine resonance risk in §6.4), against −3.0 to −3.5 hours of endurance and a new member sitting in the propwash.**

**Three better ways to get the same benefits:**

1. **Close the loop at the wing, not at the tail.** A stiff spanwise carry-through between the two boom collars, inside the wing at y = ±0.62 — where there is already structure, no drag and no propwash — takes the lateral couple out of the wing skin and into a designed member. It does not reduce boom bending (nothing can; the load has to travel forward), but it removes the peel path identified in §7.2 and costs ~0.4 kg and zero drag. **Do this regardless.**
2. **Buy the torsional frequency by reducing the panel's polar inertia instead** (§5.2): ×1.41 for free, versus ×1.55 for 3.0–3.5 hours.
3. **If the loop must be closed at the tail, close it with tail area, not with a strut.** A centre section between the boom ends at the tail station could carry the whole S_h,eff = 0.31 m² on a 1.2412 m span at a 0.25 m chord, turning the inverted-V into an H- or U-tail; the panels then become outboard fins. The tie then costs no *net* drag because it replaces area that had to exist anyway. **But it puts the horizontal surface directly in the slipstream** — good for elevator authority, and squarely into the 400 Pa excitation regime, so it would have to be sized as a fatigue article. That is a tail redesign, not a boom decision, and it is logged as open question 4.

**Bottom line: the sponsor's instinct that closing the loop helps fatigue is correct in principle and the effect is real but modest (×3–7 on joint life, ×1.55 on the torsional frequency). Given that the boom's own laminate has a 55× strain margin and the joint problem is far better solved by replacing two screws with a spigot (§7.3, which buys MS 0.54 → 94, a factor of 174), closing the loop at the tail is not the best available €/hour. Close it at the wing, fix the tail joint properly, and lighten the panel.**

### 8.4 The geometry caveat that could invert this

If the panels in fact point **inboard-and-down**, meeting at an apex on the centreline at z = −0.559 m, then:

- The loop is **already closed** for free, in panel-to-panel compression; item I is moot; the lateral bending never reaches the booms; boom torsion is restrained at the apex by the mirror-symmetry condition (θ_x = 0), which is a *rigid* restraint and pushes f_t1 far above 22.7 Hz.
- **But the panels then sweep to a minimum radius of 0.4153 m from the thrust axis** — 8.7 mm outside the propeller tip radius of 0.4065 m at the disc plane, and about 50–70 mm outside the contracted slipstream at the tail station [CALC]. That is *far* tighter than the booms' 169 mm, well inside the 0.2 D clearance guideline [16][DR], and it puts the inboard part of each panel in the blade tip-vortex path.

**Which geometry is actually intended must be settled before this pack's §6 and §8 conclusions can be relied on.** Open question 3. The recommendation if it is a free choice: **keep the panels outboard and close the loop at the wing.** The propwash exposure is the deciding factor, and it is the one thing that cannot be fixed later by adding material.

---

## 9. Question F — the 90 mm diameter is a parameter

`design/argus7_v1.yaml` tags `booms.diameter_m: 0.09` as `assumption`, carried over from "the defective artifact this phase replaces" [3]. It has never been sized.

**The scaling.** For a thin-walled tube, EI ∝ D³t and mass ∝ Dt. At constant EI, **mass ∝ 1/D²**. Boom parasite drag is proportional to wetted area, so **drag ∝ D**. The optimum is where the two exchange rates cross.

Sweep at EI = 80.7 kN·m² (§2.5) with roll-wrapped laminate properties:

| D (mm) | wall | kg/m | 2 booms | σ_ult | MS | shell-buckling MS | Δh mass | Δh drag | **Δh net** | f_b2 |
|---|---|---|---|---|---|---|---|---|---|---|
| 80 | 5.15 | 1.843 | 13.44 | 144 | 4.30 | 14.9 | −5.08 | +0.40 | **−4.68** | 57.3 |
| **90 (inherited)** | 3.33 | 1.379 | **10.06** | 156 | 3.97 | 7.9 | — | — | **datum** | 63.6 |
| 100 | 2.33 | 1.087 | 7.93 | 170 | 3.66 | 4.6 | +3.20 | −0.40 | **+2.80** | 69.1 |
| **110** | **1.71** | 0.885 | **6.45** | 183 | 3.38 | 2.8 | +5.41 | −0.79 | **+4.62** | 74.0 |
| **120** | 1.30 | 0.736 | **5.37** | 198 | 3.14 | **1.8** | +7.03 | −1.19 | **+5.84** | 78.4 |
| 130 | 1.01 | 0.624 | 4.55 | 212 | 2.92 | **1.2** | +8.26 | −1.59 | +6.68 | 82.4 |
| 140 | 0.80 | 0.536 | 3.91 | 227 | 2.73 | **0.85 — buckles** | +9.23 | −1.98 | +7.24 | 86.1 |

[CALC] Shell buckling from σ_cr ≈ 0.3·√(E_x E_y)·t/R, the 0.3 being the conventional knockdown for a real (imperfect) cylinder [EST][DR]. Drag from ΔC_D0 = 0.00188 × (D/0.090 − 1) [2] at 1.9 h per 0.001.

**Findings:**

1. **The endurance benefit of a larger diameter is monotonic and does not turn over within the feasible range.** The drag penalty (0.40 h per 10 mm) is 5–13× smaller than the mass benefit (2.0–3.2 h per 10 mm). There is no diameter at which drag wins.
2. **The binding constraint is not drag; it is minimum wall.** Below about 1.2 mm, the shell-buckling margin collapses (1.8 at 120 mm, 1.2 at 130 mm, negative at 140 mm), the tube becomes dentable in handling, and there is not enough wall for a bolted or bonded fitting.
3. **Choose 110–120 mm.** 110 mm gives a comfortable 2.8× shell-buckling margin at a stock 1.71–2.0 mm wall and is the safe answer. 120 mm gives another 1.2 h but at a 1.30 mm wall and a 1.8 margin, and needs local reinforcement everywhere anything is attached.

**Cost of going to 110 mm:**

| | Value |
|---|---|
| Boom wetted area | 2.062 → 2.520 m² (+22%) |
| Boom C_D0 share | 0.00188 → 0.00230 (9.4% → 11.5% of a 0.020 total) |
| Endurance | **−0.79 h** |
| Mass at equal EI | 10.06 → 6.45 kg → **+5.41 h** |
| **Net** | **+4.62 h (+0.19 d)** |
| Wing let-in burial, if `wing.z_offset_m` is unchanged | 19.5 mm on a 90 mm boom (21.7%) → **39.5 mm on a 110 mm boom (35.9%)** |

**The let-in is the real consequence and it needs stating carefully.** `argus7_v1.yaml` records that the wing section is only **75.2 mm thick at the boom station against a 90 mm boom**, that a through-boom is therefore geometrically impossible, and that `wing.z_offset_m = 0.008` was chosen inside a narrow [0, 0.0175] window with documented ill-conditioning of the CAD boolean at neighbouring values [3]. A 110 mm boom at the same z-offset buries 39.5 mm — **more than half the wing's local thickness** — and would foul the wing's own spar. **The diameter change must be made together with a z-offset change, and the `test_wing_boom_interference_volume_is_plausible` guard re-derived**, not by editing one number.

Recommended: **D = 110 mm with `z_offset_m` raised so the burial returns to ~20 mm (i.e. z_offset ≈ 0.018 m)**, keeping the joint architecture the sponsor already has and staying inside the documented upper bound of the usable window. That is a CAD task with a test to re-derive, not a boom task, and it is logged as open question 5. **If the geometry will not take 110 mm, 100 mm still returns +2.80 h and needs only a 2.33 mm wall.**

---

## 10. Question D — hand layup versus buying a tube

### 10.1 The fibre volume fraction argument is weaker than folklore

| Process | Consolidation pressure | Achievable Vf | Source |
|---|---|---|---|
| Hand wet layup, no bag | none | **0.35–0.42** ("generally resin rich… in excess of 100% fabric weight by resin") | [12][DR] |
| **Wet layup + vacuum bag** | **0.1 MPa max, ever** | **0.45–0.58** (0.58 with a controlled viscosity dwell, <2% voids) | [12][M][13][M] |
| Wet layup + **shrink tape** | **0.4–1.2 MPa** | 0.50–0.60 | [13][M][9][DR] |
| **Roll-wrapped prepreg + shrink tape (COTS)** | 0.4–1.2 MPa | **0.55–0.65** | [10][DR] |
| Prepreg + autoclave | 0.6–0.7 MPa | 0.58–0.62 | [DR] |

Back-calculating from the COTS tube's own datasheet density of 1.523 g/cm³ gives **Vf ≈ 0.54–0.57** [4][DS][CALC] — consistent with [10].

**The like-for-like comparison, at equal EI, D = 110 mm:**

| Route | Vf | E_x | wall | **2-boom mass** | Δ vs COTS |
|---|---|---|---|---|---|
| COTS roll-wrapped | ~0.54 | 94.7 GPa | 1.71 mm | **6.45 kg** | — |
| Hand layup, good bag | 0.55 | 100.1 | 1.61 mm | 6.12 kg | **−0.33 kg (+0.5 h)** |
| **Hand layup, realistic** | **0.50** | 91.2 | 1.78 mm | **6.61 kg** | +0.16 kg (−0.2 h) |
| Hand layup, poor bag | 0.45 | 82.3 | 1.98 mm | 7.20 kg | +0.75 kg (−1.1 h) |
| Hand layup, bad day | 0.40 | 73.5 | 2.22 mm | 7.94 kg | **+1.49 kg (−2.2 h)** |
| COTS filament-wound | ~0.54 | 72.6 | 2.26 mm | 8.50 kg | +2.05 kg (−3.1 h) |

[CALC]

**So the honest answer to "quantify the difference": it is 0.2 to 2.2 hours of endurance, not the order-of-magnitude the fibre-volume argument implies.** The reason is the one in §4.2 — for a fixed ply count, poor consolidation costs mass but not stiffness. A hand-laid boom at a *good* Vf is marginally **lighter** than the COTS tube, because it can be laid at exactly the required wall while COTS comes in 0.5 mm steps.

Note also that filament-wound tube, which the materials pack correctly identifies as torsionally superior, is **2.05 kg (3.1 h) heavier** at equal bending stiffness. For a boom whose torsional requirement is a frequency (§5.2) and whose bending requirement is the sizing case, **roll-wrapped is the right architecture and filament-wound is not.**

### 10.2 Where buying actually wins

The case for COTS is not mass. It is:

| | COTS roll-wrapped | Hand layup |
|---|---|---|
| **Builder hours, 2 booms** | **10–20 h** (cut, splice, bond fittings) | **80–130 h** (incl. one test article and the learning curve) [EST] |
| **Straightness** | 0.5–1 mm/m, controlled | whatever the mandrel is; a 4 m aluminium tube sags visibly under its own weight and must be supported at ≥5 points during cure [EST] |
| **Roundness / wall uniformity** | machine-wound, ±0.1 mm | seam ridges at every ply overlap; wall variation ±0.2–0.3 mm unless the shrink tape is applied with real discipline |
| **Repeatability boom-to-boom** | identical | two booms with different EI produce a permanently rigged-out aircraft; a 5% EI mismatch is a 5% tail-load asymmetry |
| **Defect visibility** | supplier's process control | dry spots and voids inside a closed tube are **invisible and unrepairable** |
| **Length** | **stock tops out at 2 m (EU) / 1.83–2.44 m (US)** [2][20][DS] → needs a splice or a custom mandrel order | **one-piece 3.65 m, which is the real advantage and the sponsor should be given it** |
| **Property provenance** | datasheet E_x, E_y, G_xy [4][DS] | must be coupon-tested; `materials_pack.md` §13 open question 7 already requires this even for COTS |
| **Cash, 2 booms** | €1,100–2,300 at €150–300/kg for 7.5 kg [EST][UNV]; up to €2,000–5,000 aerospace-sourced [2] | €1,200–1,700 in materials (§13) |

**The splice is the answer to the length problem and it is structurally trivial.** Put a bonded internal sleeve at 2.0 m aft of the wing rear spar, where M = 0.34 × M_root = 803 N·m:

- axial wall stress at the splice: σ = 803 × 0.055/9.90×10⁻⁷ = **44.6 MPa**
- running load into the bond: σ·t = 89.2 kN/m
- over a 110 mm (1 D) overlap each side: **0.81 MPa** of adhesive shear against 28.9 MPa [6][DS] → **MS 35**, and 2.8% of static, which is well below any adhesive fatigue threshold
- with `materials_pack.md`'s own rule (overlap ≥ 2 D, scarfed ends, 0.15–0.25 mm bondline, circumferential over-wrap) [2] the margin is larger still

[CALC] **Two 2 m stock tubes per boom, spliced at 2.0 m, is a legitimate and cheap answer** and it removes most of the length argument for hand-laying.

### 10.3 Recommendation on question D

**Buy the tube. Specify it. Coupon-test one offcut.**

For a solo builder with €60k and 18 months, whose premortem names "one pair of hands" as the second-highest failure mode [1], **70–110 hours saved for €0–600 of price difference is the trade, and it is obviously worth taking.** The mass difference (0.2–2.2 h of endurance) is real but second-order; the *variance* is the argument — a hand-laid boom can come out anywhere between 6.1 and 7.9 kg with defects you cannot see, and you will build exactly two of them with no chance to learn.

**Specify, in the purchase order:**

- **110 mm OD (or 100 mm), 2.0 mm nominal wall, roll-wrapped**
- **Layup declared: ≥ 55% of thickness at 0°/low-angle, 25–30% at ±45, remainder hoop.** Do not accept "3K twill" without a layup statement — a generic twill tube is ±45-dominated and bending-soft [2].
- **Declared E_x, E_y, G_xy and areal density**
- **Straightness ≤ 1 mm/m, roundness ≤ ±0.15 mm**
- **Length: 2 × 2,000 mm per boom, or one-piece ≥ 3,700 mm if the supplier holds a 4 m mandrel** (Carbon-Composite's 81–120 mm precision-tube range and Easy Composites' roll-wrapped range are the two European starting points [20][8][DS])
- **A 300 mm offcut from the same production run**, for the four-point bend and torsion coupon tests `materials_pack.md` §13 already requires

---

## 11. Question E — verifying the sponsor's technical claims

### 11.1 Resin — right conclusion, wrong product

**Polyurethane is correctly rejected**, and for the reasons given. Nothing here disputes it.

**But West System 105/205 is the wrong choice within the right family, on three counts:**

| | West 105/205 | Structural laminating / infusion epoxy |
|---|---|---|
| Mixed viscosity at 22 °C | **975 cP** [14][DS] | 200–600 cP (infusion), 400–900 (hand lam) [15][DS] |
| Tensile modulus | **2.81 GPa** [14][DS] | **3.0–3.9 GPa** [15][DS] |
| Tensile elongation | 3.4% [14][DS] | 1.9–5.3% [15][DS] |
| Hardener | **205 is the *fast* hardener** — 9–12 min pot life | slow/extra-slow hardeners give 40–90 min |

The sponsor's own stated requirement — "low-viscosity … does wet out dense carbon tows" — is not met by a 975 cP marine coating resin. And a 3.65 m tube with 8 plies is a **60–90 minute continuous layup**; a 9–12 minute pot life makes that physically impossible without mixing in six separate batches, which is how dry spots happen.

**Recommendation: a slow-hardener structural laminating epoxy** (PRO-SET LAM-125/226, Sicomin SR 8100 series, Resoltech 1080T, or Easy Composites' EL2/IN2 class), mixed by weight on a scale, with **a 40–90 minute pot life**. It costs the same per kilogram and it removes the most likely cause of a bad boom. The 8% modulus difference is negligible in a fibre-dominated laminate; the **viscosity and the pot life are what matter**.

**And: post-cure is mandatory.** `materials_pack.md` §5.3 already establishes this — room-temperature-cure epoxy reaches Tg 50–70 °C as cured and 80–90 °C after 12–24 h of elevated post-cure, and a dark composite surface parked in the sun exceeds 100 °C [2][19][DR]. **Post-cure the booms at 55–60 °C for ≥ 12 h before any fitting is bonded.**

### 11.2 Galvanic barrier — right, but one ply is the floor, not the answer

**The mechanism is correctly identified and it is a genuine, documented failure mode.** Carbon is cathodic to aluminium by roughly 1 V; the couple in the presence of moisture corrodes the aluminium preferentially, and the carbon's large cathodic area makes it worse.

**Aerospace practice confirms the sponsor's prescription:** "carbon fibres must be isolated from aluminium or steel using a barrier (liquid shim, glass ply, etc.)"; "any direct contact isolated with a single ply of glass on the graphite at the contact area" [11][DS][DR].

**But the sponsor's "one layer of 80–120 gsm fibreglass" is the documented *minimum*, and flight hardware routinely uses more.** A directly relevant data point: in an aerospace harness isolation application, "preliminary tests illustrated that **two plies** of glass could provide sufficient isolation … though **three plies** of glass were used as the base isolation … to ensure adequate insulation" [DR]. The reason is not electrochemical, it is manufacturing: **a single 80 gsm ply is ~0.07 mm thick and a single stray carbon tow, or a resin-starved patch, bridges it.**

Separately, the epoxy layer thickness itself matters, measurably: a 0.1 mm epoxy film on carbon reduced the galvanic corrosion rate in seawater **7-fold**, and 0.25 mm — "typical of that used in wet layup" — reduced it **21-fold** [23][M].

**The rule this produces, if any aluminium is retained anywhere near carbon:**

> **Two plies of 80–120 gsm E-glass, not one, with staggered seams, plus a resin-rich (not resin-starved) bondline of ≥ 0.2 mm. Where the interface is inspectable, one ply plus a sealant is acceptable. Where it is buried inside a closed tube for the life of the airframe, use two, and preferably do not create the interface at all.**

Which is §3.6's conclusion arrived at from a second direction: **the cheapest galvanic barrier is not having the aluminium.**

Note that this rule still applies to the recommended build — every aluminium collar, bush, spigot or fitting touching the carbon boom gets a glass ply, as `materials_pack.md` §7.4 already requires [2][22][DS].

### 11.3 Cured ply thickness — right for a mediocre bag

| Vf | Cured thickness, 200 gsm | Laminate density | UD E₁ |
|---|---|---|---|
| 0.40 | **0.278 mm** | 1,440 kg/m³ | 93.9 GPa |
| 0.45 | 0.247 mm | 1,470 | 105.3 |
| **0.50** | **0.222 mm** | 1,500 | 116.6 |
| 0.55 | 0.202 mm | 1,530 | 127.9 |
| 0.60 | 0.185 mm | 1,560 | 139.3 |

[CALC] from CPT = areal weight/(ρ_fibre × Vf), ρ_fibre = 1,800 kg/m³ [7][DS]

**The sponsor's 0.25–0.30 mm corresponds to Vf 0.37–0.44 — i.e. a bagged layup that is not much better than a hand layup.** A well-executed vacuum bag reaches 0.45–0.58 [12][M], i.e. **0.202–0.247 mm**. The sponsor's number is a safe planning figure and not a wrong one; it just means the layup schedule should be written in plies (§4.2), because the mass will vary by 20% and the stiffness will not vary at all.

### 11.4 Shrink tape versus vacuum bagging — the sponsor's "alternative" is actually the better method

| | Vacuum bag | Shrink tape |
|---|---|---|
| Consolidation pressure | **0.1 MPa, and no more, ever** — atmospheric is the hard ceiling [13][M] | **0.4–1.2 MPa** [13][M] |
| Void content | up to 7.5% in WLVB/VARTM [13][M] | lower; "parts feature a better fiber-to-resin ratio and improved physical properties" [9][DR] |
| Suitability for a 3.65 m tube | needs a 4 m bag, a 4 m sealed perimeter and a 4 m breather run; one leak anywhere loses the whole part | applied progressively; a local defect is a local defect |
| Radial uniformity on a cylinder | good in principle, but bridging at any local diameter change is a classic failure | uniform hoop compaction by construction |
| Industrial usage | general | **this is how roll-wrapped tube is actually made** [10][8][DR] |

[13][9][10]

**The sponsor lists shrink tape as an "alternative for tubes". It should be the primary method.** For a cylinder specifically, shrink tape delivers 4–12× the consolidation pressure of a vacuum bag, produces the higher Vf that shortens the wall (§10.1), and removes the single-point-of-failure that a 4 m vacuum bag represents for a solo builder.

**Practical warnings the sources make explicit:**

- **Overlap matters enormously.** "Each wrap of the tape advances only a few millimetres down the tube. Although time-consuming to do by hand, having lots of overlap in this way will provide much more consolidation pressure" — 50–75% overlap is the target [8][10][DR]. At 75% overlap on a 50 mm tape over a 110 mm tube, that is **~105 m of tape per boom**. Budget for it (§13) and budget the hours.
- **The tape leaves a helical witness ridge.** It must be sanded off, which removes some outer-ply fibre. Put a **sacrificial peel ply under the shrink tape**; strip it after cure and the surface comes off clean.
- The two are not exclusive: "for complex geometries, segmented tape application **or the use of a vacuum bag over the tape wrapping** provides more uniform consolidation pressure" [13][DR].

### 11.5 Vacuum level — right, and note what it means

25–29 inHg = 0.85–0.98 bar of the theoretical 1.013 bar. That is correct practice. It is worth stating explicitly what the number implies: **it is 0.085–0.098 MPa, i.e. one twelfth of what shrink tape delivers** [13][M]. The 25–29 inHg specification is not a target you can beat by pulling harder.

---

## 12. The recommended build — step by step

**Configuration: two hollow CFRP booms, 110 mm OD × 2.0 mm wall, no aluminium liner, COTS roll-wrapped tube, spliced at 2.0 m if bought in 2 m lengths.**

### 12.1 Materials

| Item | Spec | Qty |
|---|---|---|
| Boom tube | 110 mm OD × 2.0 mm roll-wrapped CFRP, layup declared (≥55% 0°, 25–30% ±45), E_x, G_xy declared | 4 × 2,000 mm (or 2 × 3,700 mm one-piece) |
| Splice sleeves | 106 mm OD × 2.0 mm CFRP, 260 mm long (2 D overlap + tolerance) | 2 |
| Adhesive | Loctite EA 9394 or equivalent RT-cure epoxy paste, 0.15–0.25 mm controlled bondline | ~600 g |
| Over-wrap cloth | 200 gsm 3k twill, **bias-cut at ±45** | 3 m² |
| Barrier cloth | 105 gsm E-glass plain weave | 1 m² |
| Laminating epoxy | slow-hardener structural laminating system, 40–90 min pot life | 1.5 kg |
| Bulkheads | 20 mm Rohacell 51 IG-F discs, 2 CFRP faces each | 6 |
| Wing collars | split CFRP or 7075 rings, 70 mm long, bonded + 4 × M5 through-bolts | 4 |
| Tail sockets | 50 mm ID CFRP socket, 150 mm engagement, bonded into the boom aft end | 2 |
| Tail spigots | 50 mm OD CFRP, 150 mm, bonded into the panel root fitting | 2 |
| Retention | 1 × M6 captive clamp bolt per side + 1 × 3-pin servo connector per side | 2 |

### 12.2 Procedure

**Stage 1 — Receive and verify (2 h)**
1. Measure each tube: OD at 5 stations, wall at both ends, straightness on a flat surface (accept ≤ 1 mm/m), mass per metre. **Record.** Compare the measured kg/m against the declared density; a discrepancy is your first evidence of the true Vf.
2. Cut a 300 mm coupon from the offcut. Four-point bend to measure E_x; torsion to measure G_xy. **Do not commit the tail to a tube whose properties you have not measured** — `materials_pack.md` §13 open question 7 requires this, and this pack's entire frequency analysis depends on E_x and G_xy [2].

**Stage 2 — Splice (4 h per boom, if two-piece)**
3. Mark the splice at **2,000 mm aft of the wing rear-spar station**, where M = 0.34 M_root.
4. Abrade the sleeve OD and both tube bores with 220 grit; degrease with IPA, not acetone [2].
5. Scarf/chamfer both tube ends internally over 10 mm to spread the shear peak.
6. Bond with EA 9394, 0.20 mm bondline set with three 0.2 mm nylon shim wires. Rotate the assembly through 90° every 10 minutes for the first hour so the adhesive does not sag to one side.
7. Cure 24 h at 20 °C, then **post-cure 12 h at 55 °C**.
8. Over-wrap 3 plies of bias-cut ±45 cloth, 300 mm wide, centred on the splice; peel ply over; shrink tape at 50% overlap; cure and post-cure.

**Stage 3 — Local reinforcement (5 h per boom)**
9. Bond internal bulkheads at: the forward end of the let-in, the aft end of the let-in, and 40 mm forward of the tail socket. These stop the tube ovalising under clamp load.
10. Bond the tail socket into the aft end: 150 mm engagement, EA 9394, controlled bondline, then a 3-ply ±45 external over-wrap over the whole socket length. **This is the joint that converts peel into hoop tension** [2].
11. Over-wrap the full 538 mm let-in region with 3 plies of bias-cut ±45, 360° around.
12. **Glass ply everywhere a metal fitting will touch carbon** — two plies of 105 gsm E-glass, staggered seams (§11.2).

**Stage 4 — Wing joint (6 h per boom)**
13. Fit the two split collars, one at each end of the let-in. Bond *and* bolt: the bond carries the working load, the bolts carry the peel and give you a mechanical backup.
14. Trial-fit into the wing let-in. The saddle must bear over the full 111° arc — shim with EA 9394 as a liquid shim, not with a dry gap.
15. Bond the boom into the let-in. **Rig both booms in a jig against the wing datum**, not to each other, so the two tails end up at the same incidence.

**Stage 5 — Verification before flight (3 h)**
16. **Tap test** each finished boom with the tail panel fitted. Record f_b1, f_b2 and f_t1 with a phone accelerometer or a cheap USB accelerometer and an FFT. Compare with §6.3.
17. **Static deflection check.** Hang 454 N (the limit vertical tail load) at the tail quarter chord with the wing rigidly supported. **Expect 45.8 mm of deflection and 1.29° of rotation.** More than 60 mm means the tube is not what the datasheet says.
18. **Ground run with the engine at cruise power**, accelerometer at the tail. Sweep the rpm. Look for any peak within 20% of a comb line (§6.4). This is the single test that closes out §6.
19. Weigh the finished booms. Both. If they differ by more than 100 g, find out why.

### 12.3 If the sponsor insists on hand-laying

Then do it this way and it will work:

- **Mandrel:** 110 mm OD aluminium tube, 4.2 m, supported at 5 points; 2 wraps of 25 µm FEP release film, spiral-wound at 50% overlap, with pull tails at both ends.
- **Layup:** 1 × 200 gsm twill **bias-wrapped ±45** / 6 × 200 gsm UD at 0°, seams staggered 60° between plies / 1 × 200 gsm twill bias-wrapped ±45. **Eight plies. Write the schedule in plies, not millimetres** (§4.2).
- **Consolidation: shrink tape, 50 mm wide, 75% overlap, over a peel ply.** ~105 m of tape per boom. Not a vacuum bag.
- **Resin:** slow-hardener structural laminating epoxy, weighed, applied by squeegee and consolidated ply by ply.
- **Cure** 24 h at 20 °C; **post-cure 12 h at 55 °C**; extract the mandrel **while the tube is at 40–50 °C** and the mandrel is chilled [10][DR].
- **Build a third boom first, as a test article, and destroy it.** Four-point bend it to failure. That is the only way you will know what your own layup achieves.
- Expected result: **1.78 mm wall at Vf 0.50, 3.31 kg per boom, EI 80.7 kN·m²** — or 2.22 mm and 3.97 kg at Vf 0.40, which is a 1.3 kg / 2.0 h penalty and nothing worse.

---

## 13. Bill of materials, cost and build hours

### 13.1 Recommended (COTS) route

| Item | Qty | Unit | Total |
|---|---|---|---|
| 110 × 2.0 mm roll-wrapped CFRP tube | 7.5 kg | €150–300/kg [EST][UNV] | **€1,125–2,250** |
| Splice sleeve stock (106 × 2 mm) | 0.6 m | — | €90–160 |
| EA 9394 or equivalent paste adhesive | 1 kg kit | €90–140 | €90–140 |
| 200 gsm 3k twill, bias-cut | 3 m² | €25–35/m² | €75–105 |
| 105 gsm E-glass | 1 m² | €12–18/m² | €15 |
| Slow laminating epoxy | 1.5 kg | €25–35/kg | €40–55 |
| Rohacell 51 IG-F offcut | — | — | €25 |
| Collars, bushes, fasteners, spigots/sockets | — | — | €150–300 |
| Consumables (peel ply, release film, shrink tape, gloves, mixing) | — | — | €120–200 |
| Coupon testing (or a friendly workshop) | — | — | €0–400 |
| **Total, two booms** | | | **€1,730–3,650** |

### 13.2 Hand-laid route

| Item | Qty | Total |
|---|---|---|
| 200 gsm UD carbon (6 plies × 2 booms + 30% waste) | 20 m² | €600–800 |
| 200 gsm 3k twill (2 plies × 2 booms + over-wraps, bias-cut → +40% waste) | 9 m² | €250–360 |
| Structural laminating epoxy, slow hardener | 6 kg | €160–220 |
| **Shrink tape, 50 mm** (~210 m at 75% overlap + test article) | 6 rolls | **€250–420** |
| Peel ply, FEP release film | 35 m² | €120–180 |
| Aluminium mandrel, 110 × 2 mm × 4.2 m (may be consumed) | 2 | €140–260 |
| E-glass, adhesives, fittings, consumables | — | €300–500 |
| Post-cure oven (insulated box + thermostat + heater) | 1 | €150–350 |
| Test article (3rd boom, destroyed) | — | €300–400 |
| **Total, two booms + one test article** | | **€2,270–3,490** |

**The cash difference is close to zero.** The difference is entirely in hours and in variance.

### 13.3 Build hours, solo builder

| Task | COTS | Hand-laid |
|---|---|---|
| Sourcing, specification, vendor liaison | 6–12 | 4–8 |
| Incoming inspection + coupon test | 3–6 | 3–6 |
| Mandrel preparation and support rig | 0 | 8–14 |
| Ply cutting (incl. bias cutting) | 0 | 8–12 |
| Layup | 0 | 12–20 |
| Shrink-tape wrapping | 0 | 8–14 |
| Cure, post-cure, demould, clean-up | 0 | 10–18 |
| Test article: build, test, learn, redo | 0 | **25–40** |
| Splicing (if two-piece) | 6–10 | 0 |
| Local reinforcement, bulkheads, over-wraps | 8–14 | 8–14 |
| Sockets/spigots, collars, fittings | 10–16 | 10–16 |
| Jig, rig, bond into the wing | 10–16 | 10–16 |
| Verification (tap test, deflection, ground run) | 4–6 | 4–6 |
| **Total, both booms** | **47–80 h** | **110–184 h** |
| **Midpoint** | **≈ 64 h** | **≈ 147 h** |

[EST], calibrated against the task-level structure of `materials_pack.md` §12.

**≈ 83 hours of difference.** On a programme whose premortem lists "one pair of hands, 18 months, three full-time workstreams" as failure mode #2 [1], and where the booms are perhaps 3% of the airframe by hours, this is not where the builder's time should go.

---

## 14. Consolidated endurance ledger

All figures for **two booms, 3.6456 m each**, sized to EI = 80.7 kN·m² except where noted. Baseline 112.8 h [1].

| Build | Boom tube | Local reinf. | **Total** | Δ mass h | Δ drag h | **Net Δh** |
|---|---|---|---|---|---|---|
| **Sponsor as proposed** — Al 90 × 2.0 liner + 10 "heavy duty" woven layers | 18.45 | 0.60 | **19.05 kg** | −14.8 | +0.79 | **−14.0, and 10% short of the stiffness requirement** |
| Same on a 1.5 mm liner (if a 1.5 mm wall can be sourced) | 15.94 | 0.60 | 16.54 kg | −11.0 | +0.79 | −10.2, **and 19% short** |
| Sponsor's architecture, **sized to actually meet the requirement** — Al 90 × 1.5 + 2.56 mm carbon | 15.42 | 0.60 | **16.02 kg** | −10.2 | +0.79 | **−9.4** |
| Same with a 1.0 mm liner | 13.98 | 0.60 | 14.58 kg | −8.1 | +0.79 | −7.3 |
| Hollow CFRP at the inherited 90 mm, sized to requirement | 10.06 | 1.66 | 11.72 kg | −3.8 | +0.79 | **−3.0** |
| Hollow CFRP 100 mm, sized to requirement | 7.93 | 1.66 | 9.59 kg | −0.6 | +0.40 | −0.2 |
| **Recommended — COTS roll-wrapped 110 × 2.0, two-piece spliced** | **7.54** | **1.66** | **9.20 kg** | **datum** | **datum** | **datum** |
| Same, 110 mm sized exactly to requirement (1.71 mm wall) | 6.45 | 1.66 | 8.11 kg | +1.6 | 0 | +1.6 |
| Hand-laid 110 mm, **one-piece**, Vf 0.50 | 6.61 | 1.22 | 7.83 kg | +2.1 | 0 | **+2.1** |
| Hand-laid 110 mm, one-piece, Vf 0.40 | 7.94 | 1.22 | 9.16 kg | +0.1 | 0 | +0.1 |
| COTS 120 × 1.6 (stock wall, 22% stiffness surplus) | 6.61 | 1.90 | 8.51 kg | +1.0 | −0.40 | +0.6 |
| 120 mm sized exactly to requirement (1.30 mm wall, buckling MS 1.8) | 5.37 | 1.90 | 7.27 kg | +2.9 | −0.40 | **+2.5** |
| **Optional: + faired 50 mm tail cross-tie (§8)** | | +0.75 | +0.75 kg | −1.1 | −2.4 | **−3.5** |

[CALC] Δh = −1.5·(m − 9.20) − 1900·(C_D0,boom − 0.002298), with C_D0,boom = 0.00188 × D/0.090 [2].

Local reinforcement, both booms: 2 collars 0.30 + let-in over-wrap 0.24 + 6 bulkheads 0.18 + 2 tail sockets 0.50 = **1.22 kg**, plus **0.44 kg** for two splice sleeves and their over-wraps if the tube is bought in 2 m lengths, and **+0.24 kg** at 120 mm where the thinner wall needs more local build-up. The aluminium-lined builds are credited with needing only 0.60 kg because the liner genuinely does provide the crush resistance the bulkheads and collars otherwise buy. [EST]

**Read four ways:**

- **Against the sponsor's proposal as written: +14.0 hours (0.58 days)** — and the proposal is still 10% short of the stiffness requirement, so it would have to grow further before it is airworthy.
- **Against the sponsor's architecture properly sized: +9.4 hours (0.39 days).**
- **Against the current 90 mm baseline in `argus7_v1.yaml`, properly sized: +3.0 hours**, entirely from the diameter change (+3.8 h of mass, −0.8 h of drag).
- **And a one-piece hand-laid 110 mm boom at Vf 0.50 is the lightest option on the table (+2.1 h)** — because it avoids the splice and can be laid at exactly the required wall. That is the real, honest argument for hand-laying, and §10.3 still recommends against it on hours and variance, not on mass.

For scale, `materials_pack.md` §11 puts the *entire* cost of following the sponsor's build preference across the whole wing at 16.6–23.3 h [2]. **The boom decision alone is 10–15 h of that, and it is decided by two numbers: whether the aluminium stays and what the diameter is.**

---

## 15. Open questions

**Configuration — these block conclusions in this pack**

1. **V_D is not stated in the design report.** Every tail load in §2.2 scales with q_D. 200 km/h EAS is carried over from `materials_pack.md` and is [EST]. Fix V_D and the load case is closed.
2. **The propulsion set does not close: C_P = 0.911 is required for 17 kW at 2,100 rpm on a 0.813 m propeller** (§6.2), against a physical ceiling near 0.25. Until the reduction ratio, prop diameter and rpm are reconciled, the blade-passage frequency is uncertain from ~47 to ~107 Hz and §6.4 cannot be closed. **This is the highest-value open question in the pack** and it is a propulsion question, not a structures one.
3. **Which way do the tail panels point?** Outboard-and-down (assumed here) or inboard-and-down to a centreline apex. It decides whether the structural loop is already closed (§8.4), whether the panels sit 169 mm or 9 mm from the prop tip radius, and whether §8's recommendation stands. `tail.dihedral_deg` is tagged `assumption` in the yaml [3].
4. **Should the tail be re-architected as an H/U-tail with a centre section?** It closes the loop for free, removes the cos²Γ effectiveness loss, and gives propwash over the elevator — at the price of putting the horizontal surface inside the slipstream and making it a fatigue article (§8.3). Out of this pack's scope; worth an hour of someone's time.
5. **A 110 mm boom needs `wing.z_offset_m` changed with it**, and the yaml documents that this value sits in a narrow window with an ill-conditioned CAD boolean at neighbouring values [3]. Diameter and z-offset must be changed together and `test_wing_boom_interference_volume_is_plausible` re-derived.

**Structural**

6. **The tail-joint inspection intervals in §7.3 (25 h then 50 h, replace at 2% hole elongation) are engineering judgement, not measured.** If a bolted joint is adopted, one bearing-fatigue coupon at the design bearing stress would replace judgement with data.
7. **CFRP S-N data above 10⁷ cycles is thin** and the VHCF literature reports no true fatigue limit and a step in the S-N curve at the HCF/VHCF transition [18][M]. The 55× strain margin in §6.5 is the defence, not the extrapolation — but the margin depends on the near-field pressure estimate, which is [EST].
8. **The near-field blade-passage pressure at 0.21 D tip clearance is estimated, not measured** (§6.1). A single microphone or surface-mounted pressure sensor on the boom during a ground run would replace a 20–200 Pa estimate with a number, and it is the input that decides §6.5.
9. **Structural damping ratio of the finished boom is assumed at 1–5%.** The tap test in §12.2 step 16 measures it directly from the decay envelope and costs nothing.
10. **The 111° let-in arc under lateral load has not been analysed beyond a hand couple calculation** (§7.2). It is the joint whose failure loses the aircraft. A simple FE shell model, or a static test to 1.5× limit lateral load on a boom stub, would close it.

**Supply and process**

11. **No verified vendor price for 110 mm roll-wrapped tube at ≥ 2 m.** §13's €150–300/kg is [EST][UNV]. Two quotes settle it, and the answer changes the COTS-vs-hand-lay calculus in §10.3 more than any technical argument does.
12. **Will any supplier declare E_x, E_y and G_xy and the layup?** `materials_pack.md` §4.5 already makes this the acceptance condition [2]. If nobody will, the tube must be coupon-tested and the schedule must allow for it.
13. **Shrink tape consumption is 105 m per boom at 75% overlap** (§11.4) — verify against a real trial on a 500 mm test piece before ordering, because the number is derived from the overlap geometry, not from experience.

---

## 16. Sources

| # | Source | Type |
|---|---|---|
| [1] | `docs/argus7_design_report.md` v1.0, 2026-08-20 — §2 geometry, §3 mass budget, §4 aero/performance, §5 structures, §6 powertrain, Annex A premortem | project document |
| [2] | `research/materials_pack.md`, 2026-08-20 — §4 boom sizing and tube properties, §6.8 endurance ledger and the 1.5 h/kg exchange rate, §7 adhesives and joints, §8 fatigue and environment, §13 open questions | project document |
| [3] | `design/argus7_v1.yaml` — `booms.diameter_m: 0.09` tagged `assumption`; `wing.z_offset_m` window and CAD-boolean conditioning notes; `tail.dihedral_deg` tagged `assumption` | project document |
| [4] | Rock West Composites, P/N 45285, roll-wrapped 2×2 twill + multidirectional uni tube, engineering property table (E_x 94.7 GPa, E_y 32.9, G_xy 11.68, σ_t 620 MPa, ρ 1.523 g/cm³) — https://www.rockwestcomposites.com/45285.html | [DS] |
| [5] | Rock West Composites, P/N 35165-U, filament-wound tube (E_x 72.6 GPa, G_xy 22.53 GPa), available to 15 ft — https://www.rockwestcomposites.com/35165-u.html | [DS] |
| [6] | Henkel Aerospace, "Hysol EA 9394 Epoxy Paste Adhesive" TDS — 28.9 MPa lap shear at 25 °C, **T-peel 5 lb/in = 22 N/25 mm**, Tg 78 °C dry — https://exdron.co.il/Exdron-Pdf/Loctite_Hysol_EA9394.pdf | [DS] |
| [7] | Easy Composites, "210g (6.2 oz) 2×2 Twill 3k Carbon Fibre Cloth" product data (areal weight, fibre density basis for CPT) — https://www.easycomposites.us/200g-22-twill-3k-carbon-fiber-cloth | [DS] |
| [8] | Easy Composites, "How to Choose the Best Carbon Fibre Tube for an Application" and "How to Make a Roll Wrapped Carbon Fibre Tube" (roll-wrapped = highest bending stiffness; shrink-tape overlap practice) — https://www.easycomposites.eu/learning/carbon-fibre-tubes-explained · https://www.easycomposites.co.uk/learning/how-to-make-a-roll-wrapped-carbon-fibre-tube | [DS]/[DR] |
| [9] | Dunstone Innovation, "Shrink Tape vs. Vacuum Bagging vs. Autoclave" — shrink tape pressurises by heat, shrinks up to 20%, "better fiber-to-resin ratio and improved physical properties"; used for tubing where bagging is impractical — https://www.shrinktape.com/resources/news/shrink-tape-vs-vacuum-bagging-vs-autoclave/ | [DR] |
| [10] | "Roll Wrapping Carbon Fiber Tubes: Process, Materials, and Technical Specifications" — Vf 55–65% with shrink-tape consolidation; PTFE/nylon shrink tape helically at 50–75% overlap; **mandrel extraction while the tube is still at 40–50 °C** — https://incomepultrusion.com/roll-wrapping-carbon-fiber-tubes-an-in-depth-guide/ | [DR] |
| [11] | Abbott Aerospace, AA-SB-001 §4.1.8 "General Laminate Design Guidelines" — "Carbon fibers must be isolated from aluminum or steel using a barrier (liquid shim, glass ply, etc)" — https://www.abbottaerospace.com/aa-sb-001/4-materials/4-1-composite-materials/4-1-8-general-laminate-design-guidelines/ | [DS] |
| [12] | "Optimization of the wet lay-up/vacuum bag process for the fabrication of carbon fibre epoxy composites with high fibre fraction and low void content", *Composites* (1989) — up to **58% fibre by volume and <2% voids** within a 7,500–16,500 mPa·s viscosity dwell window — https://www.sciencedirect.com/science/article/abs/pii/0010436189902139 | [M] |
| [13] | "Magnet Assisted Composite Manufacturing: A Flexible New Technique for Achieving High Consolidation Pressure in Vacuum Bag/Lay-Up Processes", *Materials* — **VARTM and WLVB consolidation pressure limited to atmospheric 0.1 MPa, void content up to 7.5%, versus 0.4–1.2 MPa processes** — https://pmc.ncbi.nlm.nih.gov/articles/PMC6101221/ | [M] |
| [14] | Gougeon Brothers / WEST SYSTEM, "Technical Data Sheet 105 System 105/205" — mixed viscosity **975 cP at 72 °F**, tensile modulus **2.81 GPa**, elongation 3.4%, 205 = fast hardener — https://www.westsystem.com/app/uploads/2022/09/105_205-207-Combined.pdf | [DS] |
| [15] | PRO-SET LAM-125/LAM-226 and LAM-1002/LAM-237 laminating & infusion epoxy TDS (tensile modulus 3.0–3.9 GPa, elongation 1.9–5.3%) — https://eu.prosetepoxy.com/wp-content/uploads/2025/04/PRO-SET-LAM-125-with-LAM-226-Medium-Cure-Laminating-Epoxy-Rev-3.pdf | [DS] |
| [16] | FAA Advisory Circular **AC 20-66B, "Propeller Vibration and Fatigue"** (3/24/11) — propeller-induced vibratory excitation, resonance avoidance and fatigue evaluation practice — https://www.faa.gov/documentLibrary/media/Advisory_Circular/AC_20-66B.pdf | [DS] |
| [17] | Resonance separation practice: "many major vibration problems can be avoided by making sure the excitation frequency does not fall within a **20 percent range** around the natural frequencies of the vibration modes of the system"; blade-passage excitation = shaft rate × blade count — ABS "Insights into Ship Vibration Analysis" and ScienceDirect "Blade Passing Frequency" overview — https://cloudstage.eagle.org/content/dam/eagle/advisories-and-debriefs/Insights%20into%20Ship%20Vibration%20Analysis.pdf | [DR] |
| [18] | "Very High Cycle Fatigue (VHCF) Characteristics of Carbon Fiber Reinforced Plastics (CFRP) under Ultrasonic Loading", *Materials* 13(4):908 — **matrix fatigue-limit strain ε_mf = 0.6% for epoxy resins, below which no damage progression occurs**; CFRP shows no traditional fatigue limit and a step in the S-N curve at the HCF/VHCF transition; matrix micro-cracking is the principal failure driver — https://doi.org/10.3390/ma13040908 | [M] |
| [19] | Composite bolted-joint bearing fatigue: "Bearing Fatigue and Hole Elongation in Composite Bolted Joints" (Vertical Flight Society); bearing failure as four-stage compressive damage accumulation with progressive hole elongation and preload loss; **typical composite design bearing allowable 24,000 ± 4,000 psi (165 ± 28 MPa)** — https://vtol.org/store/product/bearing-fatigue-and-hole-elongation-in-composite-bolted-joints-631.cfm | [M]/[DR] |
| [20] | Carbon-Composite GmbH, carbon precision tubes, outside diameter 81–120 mm, ex-stock — https://www.carbon-composite.com/en/Products/Carbon-tubes-round/Sorted-by-outside-diameter/Precision-tubes-81-120mm/ | [DS] |
| [21] | Aluminium Online / Aluminium Warehouse, 90 mm × 2 mm 6060 round tube; standard alloys 6060/6063/6082-T6, 6 m stock lengths, cut to size — https://www.aluminium-online.co.uk/product/aluminium-round-tube-90mm-x-2mm/ | [DS] |
| [22] | Clearwater Composites, "Carbon Fiber Tube FAQ — Galvanic Corrosion" (insulate carbon from metal with fibreglass) — https://www.clearwatercomposites.com/resources/faq/carbon-fiber-tubing/ | [DS] |
| [23] | Galvanic corrosion rate vs epoxy coating thickness on carbon fibre: 0.1 mm coating reduces the rate **7-fold** in seawater and 5-fold in deicing salt; 0.25 mm ("typical of that used in wet layup") reduces it **21-fold** and 23-fold — galvanic-corrosion literature on CFRP/metal couples | [M]/[DR] |

---
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

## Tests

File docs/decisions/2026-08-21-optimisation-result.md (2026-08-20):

# ARGUS-7 optimisation result and gauntlet verdict

**2026-08-21.** Gauntlet gates pre-registered 2026-08-20 before any challenger was seen.

## The result, like-for-like at 250 kg MTOW

| | v1.0 published | v1.0, honest model | **v2.0 optimised** |
|---|---|---|---|
| Endurance | 4.70 d (claimed) | **3.16 d** | **4.88 d** |
| Fuel fits the wing | No | **No** (101.5 kg into 66.1) | **Yes** (101.0 into 138.6, +37.6 margin) |
| Wing area | 3.9 m² | 3.9 m² | **5.46 m²** |
| Aspect ratio | 22 | 22 | 24.40 |
| Thickness | 13.7% | 13.7% | 17.6% |
| Span | 9.26 m | 9.26 m | 11.54 m |
| **Engine rating** | **17 kW** | 17 kW | **8.15 kW** |
| Loiter load fraction | — | **19%** | **33%** |
| Effective BSFC | 270 assumed | **425 g/kWh** | **328 g/kWh** |
| MTOW | 250 kg | 250 kg | 248.4 kg |

**The published 4.7-day claim is achievable at 250 kg — but not by the published
aircraft.** It needs a 40% larger, thicker wing and an engine less than half the size.

## The single largest lever is the engine, not the airframe

v1.0 installs 17 kW because *climb* needs it, then loiters at 3.4 kW — **19% load**,
where BSFC is 425 g/kWh rather than the assumed 270. Right-sizing to 8.15 kW lifts
load fraction to 33% and drops effective BSFC to 328. The climb constraint is then
exactly active: 8.11 kW required, 8.15 kW installed.

That tension — climb wants 12–17 kW, loiter wants 3.4 kW, one fixed engine cannot
serve both — is the central unsolved problem of this configuration, and no amount of
aerodynamic work substitutes for it.

## Gauntlet verdict on the earlier challenger: DO NOT ADOPT

G1 PASS · **G2 FAIL** · G3 PASS · G4 PASS · G5 pass-on-the-letter · **G6 FAIL** ·
**G7 FAIL** · G8 PASS. Conjunctive, so not adopted. The audit independently
re-derived endurance to **six significant figures** (171.404 h vs 171.403) — the
arithmetic was clean, the model was not.

## Four modelling errors found and fixed, all mine

1. **C_D0, e and BSFC as free variables** → optimiser returned 208.7 h by sitting in
   the corner of the box. Called in advance by the pre-registration.
2. **Raymer's Oswald correlation extrapolated to AR 22** → gave e = 0.485 against
   0.979 measured by AVL. Fixed with a surface fitted to 45 AVL runs, which showed
   span efficiency is nearly *flat* in aspect ratio.
3. **Wing thickness unpriced** → bought at 40% of its true drag cost. Fixed with a
   NeuralFoil measurement on the actual coordinates (+15.8% profile drag at t/c 0.20,
   and C_Lmax *rises* 1.868 → 1.973).
4. **Tank capacity understated 1.68×** → conflated fraction-of-chord with
   fraction-of-area, and fraction-of-span with fraction-of-volume. A 15–65% chord box
   holds **71.6%** of section area; the inner 80% of a taper-0.30 span holds **94%**
   of volume. Found by the audit, confirmed by integrating the real coordinates.

Every one was a constant used outside the regime it was fitted for, and every one was
caught by checking against an independently measured value rather than by the number
looking plausible. **208.7 h looked like a world record.**

## Also found: two of the report's own sensitivity anchors are wrong

The audit checked all three. C_D0 −0.004 → +0.358 d against the report's +0.36 d ✓.
But BSFC 250 gives **+0.377 d, not +0.5 d**, and 3,000 m gives **+0.198 d, not
+0.23 d**.

## Bounds still pinned, and what that means

The 320 kg unconstrained optimum (6.63 d) pins MTOW, span and thickness. Endurance
against the MTOW cap, engine right-sized throughout:

| MTOW cap | Endurance | Engine | Load | BSFC |
|---|---|---|---|---|
| 200 kg | 3.36 d | 6.70 kW | 38.6% | 313 |
| **250 kg** | **4.88 d** | 8.15 kW | 33.0% | 328 |
| 280 kg | 5.64 d | 9.13 kW | 31.7% | 333 |
| 320 kg | 6.25 d | 10.43 kW | 30.3% | 342 |

Endurance buys almost linearly with MTOW, so "how long can it fly" is really "how
heavy may it be" — a regulatory and operational question, not an aerodynamic one.

## Not yet modelled

- **The propeller cannot absorb its rated power.** C_P = 0.911 against a ~0.25
  ceiling at the v1.0 point. Neither design is flyable as specified until this is
  resolved; a right-sized 8 kW engine helps but does not by itself close it.
- Cruise-climb and transit; pure loiter only.
- Non-wing airframe mass fixed at 28 kg regardless of size.
- The 5–7 day target needs 250 kg+ **and** the propulsion set to close.

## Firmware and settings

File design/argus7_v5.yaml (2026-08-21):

# ARGUS-7 v5.0 - span-corrected. v4.0 sat at 12.001 m against a 12.0 m limit,
# i.e. zero buildable margin, and failed gate G3 by 1 mm. This run targets
# 11.85 m, leaving 144 mm.
# Propeller solved AT THIS DESIGN POINT, not inherited -- v3.0 and v4.0 both
# carried v2.0's propeller and were 26% and 19% short of level-flight thrust.
name: ARGUS-7
variant: v5.0
mission:
  payload_mass_kg: 50.0
  payload_power_w: 500.0
  loiter_altitude_m: 4000.0
wing:
  area_m2: 5.7201
  aspect_ratio: 24.5728
  taper_ratio: 0.25
  airfoil: FX63-137
  twist_tip_deg: -3.0
  dihedral_deg: 3.0
  sweep_le_deg: 1.0
  thickness_ratio: 0.22
  incidence_deg: 2.0
  x_le_frac: 0.4075
  z_offset_m: 0.008
fuselage:
  length_m: 3.4
  max_diameter_m: 0.48
  stations:
  - - 0.0
    - 0.15
  - - 0.08
    - 0.62
  - - 0.22
    - 1.0
  - - 0.55
    - 0.96
  - - 0.8
    - 0.7
  - - 1.0
    - 0.34
booms:
  diameter_m: 0.09
  y_station_frac: 0.134
  clearance_m: 0.15
tail:
  type: inverted_v
  area_h_m2: 0.3222
  arm_m: 5.7732
  dihedral_deg: -42.0
  taper_ratio: 0.55
  airfoil: NACA0010
  panel_aspect_ratio: 3.0
propulsion:
  engine_displacement_cc: 250.0
  power_max_kw: 10.849
  reduction_ratio: 3.659
  prop_diameter_m: 1.04
  prop_rpm: 2050.0
  prop_blades: 2
  prop_pitch_ratio: 0.95
  prop_eta_loiter: 0.8529
masses:
  airframe: 68.63
  powertrain: 15.95
  avionics: 6.0
  recovery: 7.0
  payload: 50.0
  fuel: 172.42
  mtow: 320.0
aero:
  cd0: 0.0169
  oswald_e: 0.8101
  cl_max: 1.6
provenance:
  wing.area_m2: derived
  wing.aspect_ratio: derived
  wing.taper_ratio: derived
  wing.airfoil: "report-\xA72"
  wing.thickness_ratio: derived
  wing.twist_tip_deg: assumption
  wing.dihedral_deg: assumption
  wing.sweep_le_deg: assumption
  wing.incidence_deg: assumption
  wing.x_le_frac: derived
  wing.z_offset_m: assumption
  fuselage.length_m: assumption
  fuselage.max_diameter_m: assumption
  fuselage.stations: assumption
  booms.diameter_m: assumption
  booms.y_station_frac: assumption
  booms.clearance_m: assumption
  tail.type: "report-\xA72"
  tail.area_h_m2: derived
  tail.arm_m: derived
  tail.dihedral_deg: assumption
  tail.taper_ratio: assumption
  tail.airfoil: assumption
  tail.panel_aspect_ratio: assumption
  propulsion.engine_displacement_cc: "report-\xA72"
  propulsion.power_max_kw: derived
  propulsion.reduction_ratio: derived
  propulsion.prop_diameter_m: derived
  propulsion.prop_rpm: derived
  masses.airframe: derived
  masses.powertrain: derived
  masses.avionics: "report-\xA73"
  masses.recovery: "report-\xA73"
  masses.payload: "report-\xA73"
  masses.fuel: derived
  masses.mtow: derived
  mission.payload_mass_kg: "report-\xA71"
  mission.payload_power_w: "report-\xA71"
  mission.loiter_altitude_m: derived
  aero.cd0: derived
  aero.oswald_e: derived
  aero.cl_max: "report-\xA74"
  propulsion.prop_blades: derived
  propulsion.prop_pitch_ratio: derived
  propulsion.prop_eta_loiter: derived

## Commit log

2026-08-20 Set up repo structure and spec CAD/sim/optimisation work
    Organise the delivered zip into docs/, research/, model/, figures/,
    archive/; fix stale /mnt/agents/output paths so figures resolve; add
    README documenting the two design points and known gaps.
    Add design spec for rebuilding the CAD model and standing up a
    simulation + optimisation stack. Motivated by three defects in
    model/argus7_model.scad: wing and fuselage share an axis, geometry is
    the superseded pre-correction Gemini set (S +16%, AR -13.8%), and the
    wing has no airfoil section.
    Add toolchain bootstrap (xfoil, gmsh, calculix, openscad, AVL, SU2).
    [argus7_model.scad]
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2026-08-20 fix(setup): correct AVL build paths in bootstrap
    plotlib builds via 'make -C plotlib gfortran' (a target, not a
    Makefile variant) and the top-level Makefile lives in bin/. Both
    failures were hidden by output suppression in an && chain.
2026-08-20 fix(design): machine-check parameter provenance, correct false report claim
    Round-1 review finding: fuselage.length_m, fuselage.max_diameter_m,
    booms.length_m and tail.dihedral_deg were transcribed from
    model/argus7_model.scad (the defective artifact this phase replaces)
    while the file header claimed the whole file was as-published in
    report section 2. That claim was false for those four fields.
    Adds a provenance: block tagging every wing/fuselage/booms/tail/
    propulsion field as report-§2, design_pack-§1, derived, or assumption,
    enforced by a new test that fails if any field lacks a tag (verified
    by temporarily removing one and watching it fail). booms.length_m is
    tagged derived per rulin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
    [argus7_v1.yaml]
2026-08-20 feat(cad): airfoil coordinate library with NACA4 generator
    Real section coordinates replace the sphere-hull massing that stood in
    for an airfoil (Defect 3). Twist rotates about the leading edge.
    Two corrections against the task-2 brief, both required for the real
    UIUC fx63137.dat and physically-correct washout:
    - load_airfoil auto-detects Selig vs. Lednicer .dat format. The real
    fx63137.dat is Lednicer (point-count header + two LE->TE surface
    blocks), not Selig as the brief assumed; naively parsing it yields a
    bogus t/c of 1.0000. Detection: first pair value > 1.0 => Lednicer,
    header dropped and surfaces reassembled into Selig order. Measured
    t/c = 0.13712, max camber = 0.05968.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
2026-08-20 fix(cad): validate Lednicer surface split against header point counts
    Fix round 1 finding (Important): load_airfoil parsed the Lednicer
    point-count header only to detect the format, then discarded it. The
    upper/lower split was found solely by the "first x-decrease" heuristic,
    with no check against the header's declared counts -- a file with a
    non-monotonic surface would silently mis-split with no error. Flagged
    as an open risk in the task-2 report; ruled to fix now (not defer)
    because Phase 2 ingests three more UIUC Lednicer sections (S1223, E387,
    SD7037) where a silent mis-split would corrupt a drag polar plausibly
    enough to be expensive to trace back.
    load_airfoil now captures n_upper/n_l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
2026-08-20 feat(cad): lofted wing with real sections, twist and dihedral
    Includes the Defect 1 regression guard: the wing must span along y and
    be spanwise-dominant, which the original SCAD model was not.
    Deviates from task-3-brief.md in three ways, all verified empirically
    against the installed build123d 0.11.1 and this project's actual design
    values (design/argus7_v1.yaml, FX63-137 airfoil):
    - RULING P12 (pre-authorized): wing.is_valid is a property, not a
    method, in build123d 0.11.1. test_wing_solid_is_valid asserts
    `wing.is_valid` with no parentheses.
    - RULING P13 (pre-authorized): tightened the area regression guard's
    tolerance from rel=0.15 to rel=0.03.
    - Beyond the two pre-authorized rul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
2026-08-20 feat(cad): fuselage, booms, inverted-V tail and installed items
    Fuselage runs along x, wing spans y - the perpendicularity is now an
    explicit test, closing Defect 1.
    Deviates from the task-4 brief per four rulings:
    - P2: tail arm is measured wing-AC to tail-AC (the standard convention,
    and the only reading under which the report's 3.2 m arm and its tail
    volume coefficient are the same quantity), not as an absolute
    nose-referenced x. Adds wing_le_x/wing_ac_x/tail_qc_x to
    design/geometry.py; for argus7_v1 x_tail_qc = 4.0936 m.
    - P15: booms.length_m is deleted as a YAML input (its old value, 3.2,
    came from the defective SCAD and cannot span wing to tail) and
    becomes derived geome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
    [argus7_v1.yaml]
2026-08-20 refactor(cad): reuse derive_booms for build_tail's boom y-station
    Self-review cleanup: build_tail recomputed y_boom with the same formula
    derive_booms already encapsulates. Reuse it instead of duplicating the
    formula, so the two can't silently drift apart.
2026-08-20 fix(cad): promote hardcoded fuselage/tail/boom geometry to design YAML
    Fix round 1 of Task 4 review (Quality: Changes Requested). Three
    findings, all the same defect class -- geometry hardcoded in Python
    that must live in design/*.yaml:
    - Finding 1 (Important): build_fuselage's six (x_fraction,
    radius_fraction) OML loft stations, defining the entire fuselage
    hull shape, are now fuselage.stations in the YAML.
    - Finding 2 (Important): build_tail's bare "AR 3" tail panel constant,
    which propagates into c_root/c_tip/panel_span, is now
    tail.panel_aspect_ratio.
    - Finding 3 (Minor): derive_booms's bare 0.15 clearance margin is now
    booms.clearance_m.
    All three get `assumption` provenance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
    [argus7_v1.yaml]
2026-08-20 feat(cad): STEP/STL export and generated OpenSCAD
    The .scad header is emitted from loaded parameters, so it cannot drift
    from the geometry it describes.
    Deviates from the task-5 brief per rulings P16/P17/P5/P6: booms and
    fuselage geometry are read from derive_booms()/design.fuselage.stations
    instead of the deleted booms.length_m field and hardcoded fractions; the
    inverted-V tail is emitted so the viewer depicts the same aircraft as the
    STEP/STL; the section() module draws the airfoil and extrudes/rotates in
    the verified spanwise-correct order; and only the imports actually used
    (_section_coords, not load_airfoil/naca4) are pulled in.
    export_model also tags the STEP unit as metres (build123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
2026-08-20 fix(cad): correct openscad twist sign and fuselage overshoot, add scale guards
    Fix round 1 (4 findings from independent review of commit c02a5eb):
    Finding 1 (important): the emitted wing twist was sign-inverted relative
    to argus7.cad.airfoil_coords.scale_airfoil's washout convention (RULING
    P4) -- OpenSCAD's rotate([0,0,twist]) is a CCW rotation in its local XY
    plane, opposite to scale_airfoil's own rotation, so the raw twist angle
    had to be negated on the way out. Measured on the rendered tip station:
    trailing edge was 1.37 cm below the leading edge (washin) before the fix,
    1.37 cm above (washout, correct) after. Added
    test_openscad_rendered_wing_tip_shows_washout, mirroring
    test_negative_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
2026-08-20 Add materials and manufacturing research pack
    Evaluates the sponsor's carbon-tube-and-3D-print build premise against
    the report's 32.5 kg wing budget and the FX 63-137 laminar requirement.
    31 sources.
    Headline results: pultruded UD spar caps and COTS booms are the right
    call; a round-tube wing spar costs 2.07x a cap-and-web spar; printed
    and film skins both fail mass closure. Surface-waviness tolerance at
    Re 0.6-1.1M is ~6x looser than the sailplane rule of thumb, and
    measured moldless homebuilt wings pass it with 2.6-4.9x margin, so a
    garage build can hold laminar flow.
    Mass-to-endurance exchange rate: 1.5 h/kg.
    Also finds the wing cannot hold its own fuel: ~143 L gross internal
    volume,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
2026-08-20 feat(cad): regenerate model from design file, retire hand-edited SCAD
    Replaces the defective hand-written model. All four defects now carry
    regression tests: wing/fuselage axis collision, superseded chords,
    missing airfoil, and hand-written headers.
    Adds argus7/cad/render.py (top/side/front/iso OpenSCAD renders) and
    scripts/build_model.py (one-command regeneration of STEP/STL/SCAD/PNGs).
    The front/side camera angles in render.py's VIEWS were corrected from a
    naive guess after rendering both and checking actual pixel bounding
    boxes -- the guess had them backwards. tests/test_cad_render.py guards
    against the renders silently going blank in the future (checks pixel
    variance and non-background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
    [argus7.step, argus7_model.scad]
2026-08-20 docs(cad): fix round 1 - restore source-code gap, reconcile fuel numbers, untrack STEP
    Three documentation/hygiene fixes from independent review (SPEC approved,
    no correctness bugs):
    - README "Known gaps": restore the dropped "no source code" bullet,
    rewritten to distinguish what P1 closed (CAD is now reproducible from
    design/argus7_v1.yaml) from what's still missing (the report's
    performance/mission analysis and figures/design-pack/fig1-9, Phase-3 work).
    - Reconcile the fuel-volume finding: research/materials_pack.md's 160 L
    gross figure uses a hardcoded 0.68 airfoil shape factor already proven
    wrong for FX63-137 in Task 3 (true value 0.6062, shoelace-integrated --
    see test_win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
    [argus7.step]
2026-08-20 Amend spec with materials and manufacturability workstream
    Materials and build method were absent from the original spec but are
    not a downstream detail: the wing mass model and achievable C_D0 both
    depend on them, and both feed the endurance objective directly.
    Adds section 7b carrying the load-bearing results from
    research/materials_pack.md, including the 1.5 h/kg mass-to-endurance
    exchange rate, the measured laminar surface tolerance (~6x looser than
    the sailplane rule of thumb, and passed by moldless homebuilt wings
    with 2.6-4.9x margin), and the finding that the wing is
    stiffness-critical rather than strength-critical.
    Adds assumption A4 recording that the wing cannot hold its specifi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
2026-08-20 docs(cad): fix round 2 - update stale fuel figure in Sec 13, flag second restatement
    Sec 13 item 8 "Open questions" still quoted the pre-correction 56-72 L
    usable-fuel figure verbatim with no pointer to the Sec 2.5 correction note
    added in fix round 1 -- exactly the failure mode that finding existed to
    kill. Updated to ~50-64 L with an explicit cross-reference to the
    correction note.
    While sweeping the rest of the file for other restatements, found a
    second one the round-1 fix hadn't caught: Sec 6.6 (moldless foam core)
    reuses the same stale "Gross wing volume 0.160 m3" for an unrelated
    purpose (core mass, not fuel), which cascades into Sec 10's build-option
    comparison table (Option E) and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
2026-08-20 fix(cad): C1 - close the wing/boom air gap, assemble one connected airframe
    The whole-branch review found build_aircraft returned FOUR disjoint solids:
    fuselage+wing+items, port boom+tail panel, starboard boom+tail panel, and a
    prop disc floating 50 mm aft. The booms -- which carry the entire tail --
    touched nothing. Measured at the boom station y = 0.6206 m: wing lower
    surface z = 0.0708 m against a boom top of 0.0450 m, a 25.8 mm air gap, with
    (wing & booms).volume == 0.
    Root cause: a hardcoded 0.05 m wing z-lift in build_aircraft, typed a second
    time in to_openscad. Ruling P15 fixed this defect class LONGITUDINALLY
    (test_booms_carry_both_wing_and_tail checks only x_fwd < x_wing_le and
    x_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
    [argus7_model.scad]
2026-08-20 test(cad): C2 - pin the committed .scad byte-for-byte against the design file
    The tracked .scad is the only geometry artifact in git (STEP/STL are
    gitignored build output) and the one the README and report point readers at,
    but the only thing tying it to design/argus7_v1.yaml was
    test_committed_model_matches_the_design_file, which samples exactly two
    derived numbers (c_root and MAC) as 4-dp substrings.
    Demonstrated: with tail.taper_ratio edited 0.55 -> 0.60 and no rebuild, this
    new test is the ONLY one of 63 that fails. The review's own demonstration
    (dihedral_deg 3.0 -> 6.0, booms.diameter_m 0.09 -> 0.14) left all 57
    pre-C1 tests passing.
    Distinct from Defect 4, which P1 genuinely fixed: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
2026-08-20 fix(cad): I3 - wire wing.incidence_deg into the built geometry
    `grep -rn incidence argus7/` returned exactly one hit: the schema
    declaration. section_stations set twist = f * twist_tip_deg, so root twist
    was 0 and the built wing had 0 deg incidence while design/argus7_v1.yaml
    declares 2.0. The provenance test cannot catch this: it checks that a tag
    EXISTS, not that the field ARRIVES.
    Phase 2 generates AVL from the same YAML and would apply the incidence; the
    STEP that SU2 meshes would not have carried it -- a 2 deg disagreement
    between two sides of a three-way C_D0 gate whose threshold is 15%.
    twist = radians(incidence_deg) + f * radians(twist_tip_deg), each section
    still rotated about its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
    [argus7_model.scad]
2026-08-20 fix(cad): I4, I6a, I5 - promote the wing station, harden is_valid, share the tail derivation
    I4 -- the last load-bearing geometry literal. The Task-4 sweep promoted
    three constants and declared the class closed; it missed
    `return 0.22 * design.fuselage.length_m` in geometry.wing_le_x, which is more
    load-bearing than any of the three it did promote: wing_ac_x, tail_qc_x, all
    of derive_booms and the tail placement are measured from it. Promoted to
    design.wing.x_le_frac (provenance: assumption). Guarded behaviourally --
    perturbing the field must move the wing station and every derived station by
    exactly the same amount, so a surviving literal shows up as a term that fails
    to move. No geometry c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
    [argus7_v1.yaml]
2026-08-20 test(design): M7 - provenance covers every design file and every section
    Two holes in the old guard, which was one test hardcoded to
    design/argus7_v1.yaml over {wing, fuselage, booms, tail, propulsion}:
    1. design/argus7_v2.yaml -- a committed deliverable the spec requires,
    produced by the optimiser -- would have loaded with no provenance block at
    all. The test is now parameterised over every design/*.yaml (with a guard
    against the glob going empty and passing vacuously). Verified by dropping
    a provenance-free v2 into design/: both provenance tests fail on it.
    2. masses, mission and aero carried ZERO provenance entries and the test did
    not ask for any -- including aero.cd0 = 0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
    [argus7_v1.yaml]
2026-08-20 test(data): M8 - pin airfoil coordinates by checksum, delete the dead naca0010.dat
    data/airfoils/fx63137.dat is load-bearing far beyond the loft: its shoelace
    shape factor 0.6062 drives test_wing_planform_area_matches_spec, the ~143 L
    gross wing volume in README.md, and two corrections in
    research/materials_pack.md §2.5. It had no checksum test, and UIUC ships
    several FX 63-137 variants -- a swap to one with the same 13.7% t/c passed
    every existing check while silently moving the shape factor, the wing volume
    and the fuel-volume conclusion currently escalated to the sponsor.
    Adds data/airfoils/MANIFEST.md (source URL, retrieval date, format, points,
    t/c, sha256, plus the derived camber/are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
2026-08-20 fix(cad): pre-merge hardening - derived interference floor, tracked caveat, washout precondition
    Three re-review items. wing.z_offset_m is UNCHANGED at 0.008.
    1. `(wing & booms).volume > 0` is not sufficient. Reproduced the sweep: OCCT
    is ill-conditioned near this joint in two distinct ways -- at z_offset
    0.006 it returns 0.0 cm3 and three disconnected solids (caught loudly),
    and at 0.010-0.012 every structural guard PASSES while the joint silently
    fails to merge and the fused solid over-counts by ~390 cm3.
    test_stl_repair_preserves_volume cannot see that: both sides derive from
    the same bad solid and the error is 0.06% against a 1% tolerance. That
    ships a defective B-r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
    [argus7_v1.yaml]
2026-08-20 Preserve Phase 1 decision record
    28 rulings made during Phase 1 execution, with reasoning and
    cost-if-wrong for each. The execution ledger was scratch; this is the
    part worth keeping for Phase 2.
2026-08-20 Record tail ground-clearance finding and prop clearance check
    The inverted-V tail hangs 385 mm below the fuselage keel. With
    parachute recovery and no landing gear it contacts the ground before
    the airbag and crush keel on every recovery. The configuration is
    never justified in the report or the design pack, and its one real
    advantage (proverse roll-yaw coupling) is worth little on an aircraft
    specified for gentle turning only. Upright-V and A-frame alternatives
    noted; trade deferred to Phase 2.
    Prop/boom clearance verified adequate at 169 mm per side.
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2026-08-20 Add optimised v2.0 design point at 4000 m
    Sponsor fixed loiter altitude to 4000-4500 m for smooth air. The
    unconstrained optimum was 2500 m at 7.14 d; the constraint costs about
    10 h, and within the band 4000 m beats 4500 m (6.73 vs 6.59 d), so the
    optimiser sits at the bottom.
    published v1.0 : 4.70 d published, 4.98 d under this model, INFEASIBLE
    (needs 101.5 kg of fuel, wing holds 39.3 kg)
    optimised v2.0 : 6.73 d at 4000 m, fuel 123.9 kg into 123.9 kg capacity
    S 6.000 m2, AR 18.74, taper 0.300, t/c 0.200, span 10.60 m, MTOW 277.2 kg.
    Tail area scaled to hold v1.0's tail volume coefficient Vh = 0.5765.
    The constraint is exactly active, so there is zero ullage margi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
    [argus7_v2.yaml]
2026-08-20 Final optimisation result and gauntlet verdict
    Like-for-like at 250 kg MTOW: published v1.0 gives 3.16 d under the
    honest model and cannot hold its fuel; the optimised v2.0 gives 4.88 d
    with 37.6 kg of tank margin.
    The published 4.7-day claim is achievable at 250 kg, but not by the
    published aircraft - it needs a 40% larger, thicker wing and an engine
    less than half the size.
    The single largest lever is the engine. v1.0 installs 17 kW for climb
    then loiters at 19% load where BSFC is 425 g/kWh, not the assumed 270.
    Right-sizing to 8.15 kW lifts load to 33% and BSFC falls to 328.
    Gauntlet verdict on the earlier challenger: DO NOT ADOPT (G2, G6, G7
    fail). The audit re-derived endurance to si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
    [argus7_model.scad]
2026-08-20 Generate v2.0 CAD into model_v2/ and figures/cad_v2/
    The regression guard caught a real drift: generating v2 CAD had
    overwritten model/argus7_model.scad, so it no longer matched
    design/argus7_v1.yaml. That is exactly the failure mode the
    byte-identical guard exists for, and it fired on the first real
    occurrence. Committed model restored to v1; v2 artifacts now live in
    their own directories.
    [argus7_model.scad, argus7_v2.scad]
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2026-08-20 Select the propeller; the propulsion set now closes
    BEMT sweep over ~400 configurations requiring BOTH loiter efficiency and
    climb power absorption. Selected: 1.00 m, 2 blades, 1900 rpm, p/D 1.05 -
    eta_loiter 0.852, absorbs 99.0% of the 8.15 kW rating, tip Mach 0.30,
    76 mm boom clearance, reduction 3.95:1.
    The published set could not close: 0.813 m at 2100 rpm against 17 kW
    needs C_P 0.911 versus a ~0.25 ceiling, absorbing about 4.7 kW of 17.
    But the propeller was never the real defect - it was being asked to
    absorb an engine sized for climb. Right-sizing to 8.15 kW more than
    halved the requirement and an ordinary 1.0 m prop then takes it. 34 of
    100 candidates satisfy both points; for the p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
    [argus7_v2.yaml]
2026-08-21 Add layout optimisation, balance analysis, and the scaling non-result
    Adds the three layout variables the earlier optimiser lacked - wing
    station, tail volume, tail arm - and makes static margin a hard
    constraint at both full fuel and dry. This was the sponsor's correction:
    the GPU should find the configuration, not have the wing hand-moved
    afterwards.
    Result: stable designs exist and are cheap to find once layout is in the
    search. v3.0 at 313 kg gives 6.33 d with SM +5.79% full / +5.71% dry and
    CG travel -0.08% MAC, verified against the authoritative balance module.
    Stability cut the feasible fraction from 25.6% to 0.45%, which is why it
    had to be a constraint rather than a post-hoc check.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
    [argus7_v2.yaml, argus7_v3.yaml]
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2026-08-21 Retire v2.0: statically unstable and its mass budget does not close
    Superseded by v3.0. Kept as the record of an intermediate optimiser
    output: SM -8.66%/-23.52% MAC against a 5-15% requirement, and 13.02 kg
    (5.2% of gross) unallocated from a double-applied engine-mass credit.
    The missing mass belongs aft, so allocating it worsens the instability.
    [argus7_v2.yaml]
2026-08-21 Rewrite README for the current state; add regenerable design figures
    The README described v1.0 as the design, called the fuel-volume problem
    unresolved, and contained a self-contradiction about the booms and the
    propwash. It now carries the design lineage (v1 published-and-defective,
    v2 retired, v3 superseded, v4 current), the five findings that moved the
    numbers, and an honest figures inventory distinguishing what is
    regenerable from what is not.
    Adds scripts/make_figures.py and figures/current/: static margin across
    the fuel burn, part-load BSFC with both design points marked, endurance
    by design point, and the induced-vs-parasite drag split. Palette
    validated (all checks pass; the contra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
    [argus7_v4.yaml]
2026-08-21 Re-solve v4.0's propeller at its own condition; add aircraft images
    THE DEFECT, found by the premortem: v3.0 and v4.0 both carried v2.0's
    propeller. scripts/prop_design_sweep.py and prop_refine.py load
    argus7_v2.yaml and hard-code v1.0's boom station, so the selection was
    never re-run for the later design points. At 1900 rpm the 1.04 m disc
    makes 61.4 N against the 76.0 N v4.0 needs for level flight - a 19%
    thrust shortfall. v3.0 was 26% short.
    Re-solved at v4.0's own operating point (101.7 km/h, 4000 m): 1.04 m,
    2 blades, 2050 rpm, p/D 0.95, thrust 85.1 N (+12% margin), eta 0.851,
    absorbs 100.3% of the 11 kW rating, reduction 3.659:1 (was 3.947, which
    was v2.0's). Balance re-verified: +12.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
    [argus7_v4.scad]
2026-08-21 Add v5.0: first design point to pass all nine adoption gates
    The span-corrected optimiser run had completed and was never used. v4.0
    sat at 12.001 m against a 12.0 m limit - zero buildable margin, failing
    gate G3 by 1 mm. v5.0 targets 11.85 m and lands at 11.856, leaving
    144 mm.
    Propeller solved AT THIS DESIGN POINT rather than inherited: 1.04 m,
    2050 rpm, p/D 0.95, thrust 84.1 N against 76.4 N needed (+10%), eta
    0.853, absorbs 99.9%, reduction 3.659:1.
    Gauntlet: 9/9 PASS, ADOPT.
    G1 endurance +120.4% G2 fuel fits (+18.0 kg) G3 span 144 mm margin
    G4 mass closes 0.00 G5 structural scaling G6 band declared
    G7 buildable AR 24.6 G8 stall margin G9 SM +12.72/+13.68%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
    [argus7_v5.scad]
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
